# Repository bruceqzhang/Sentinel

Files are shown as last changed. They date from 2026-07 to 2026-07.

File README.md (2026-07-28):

# Sentinel - Remote-Controlled FPV Tank

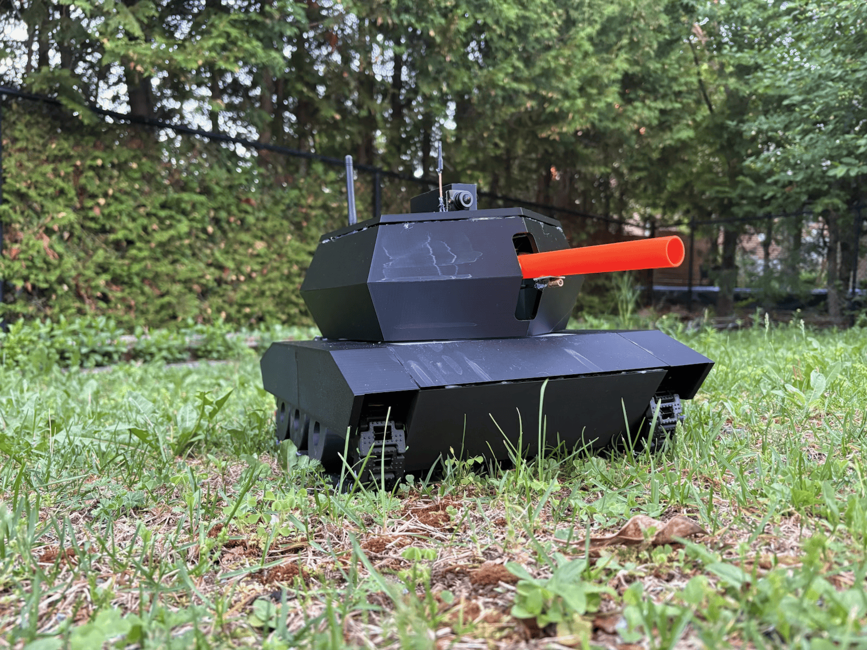
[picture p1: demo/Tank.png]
Finished Tank Design


Sentinel is a custom-built tracked remote-controlled vehicle designed and engineered from the ground up. The project combines mechanical design, embedded systems, wireless communication, and robotics into a single platform.

Built as a personal engineering challenge, Sentinel features a 3D-printed chassis, tracked drivetrain, 2.4 GHz wireless control system, 5.8 GHz FPV camera system, and a rotating Nerf turret. The tank is controlled by an Arduino-based embedded system, with future plans for onboard computer vision and autonomous capabilities using a Raspberry Pi.

The project involved designing the mechanical structure in CAD, fabricating custom parts, integrating electronics, developing the control software, and debugging a complex system of motors, sensors, and communication protocols.

## Motivation

Sentinel began as a challenge taken by two friends to build something beyond a typical classroom robot. Rather than creating a simple automated device, we wanted to explore how mechanical design, electronics, and software could come together in a complete robotics system.

## Features
- Custom 3D-printed tracked chassis
- Wireless remote control using 2.4 GHz communication
- Live 5.8 GHz analog FPV video transmission
- 360° rotating turret mechanism
- Arduino-based motor and actuator control
- Modular electronics and power distribution system
- Designed for future computer vision integration

## Technologies Used

### Hardware
- Arduino UNO R4 WiFi
- nRF24L01 wireless modules
- FPV camera, FPV monitor, and 5.8 GHz video transmitter
- Xbox controller
- DC gear motors and drivers
- Servo motors
- Stepper motor and driver
- 7.4 V 2S Li-ion battery supply
- Custom 3D-printed components

### Software
- Arduino C/C++
- Libraries including RF24, Servo, SPI, AccelStepper, XBOXONE from USB Host Shield 2.0

## Additional Resources

### CAD: 
[Onshape Project](https://cad.onshape.com/documents/b79e3abf584a43eee74fb859/w/d53a2419a0c5a431a686b558/e/01db5a0ad86b4068f335d182)  

### Weekly Journals:
[Week 1](https://docs.google.com/document/d/17Ajz8vXUG7C8QsSIpln7xRcLZVNVRcxvSVOUbZ24IYE/edit?usp=drive_link)  
[Week 2](https://docs.google.com/document/d/1W2MT0a_K2rhyGGTUNjvPy9FhipLKN2GWRZDyP753SX8/edit?usp=drive_link)  
[Week 3](https://docs.google.com/document/d/1quGVF-udUrTEX0IsD0kGBSyIRfxL883lqCnuZsB9mRc/edit?usp=drive_link)  
[Week 4](https://docs.google.com/document/d/1nc7bcCtwF5eugCoS6nO4E-aOTwUAF1d3NM4IUmDgt2E/edit?usp=drive_link)  
[Week 5](https://docs.google.com/document/d/1DuefWYwJcpw5OrmmurFnuGTMt__FWnk-4Q0KD2fvWug/edit?usp=drive_link)  
[Week 6](https://docs.google.com/document/d/11cAzaXNtNuGknSWchcGKMZekuylMzRt6ZZdopK9-in4/edit?usp=drive_link)  
[Week 7](https://docs.google.com/document/d/1Xcf18F4qVJCFmCrfTtPlUHFmC-JLRS2L01wTzXku7aY/edit?usp=drive_link)  
[Week 8](https://docs.google.com/document/d/1gu44P50zj96eCYETs0mco7hnURLjBjI5FsbhsaJNU7Q/edit?usp=drive_link)  
[Week 9](https://docs.google.com/document/d/1yQiESRAvD3YaRqxrGDqdF1br9n9rZQMoo9KKtbfv1E4/edit?usp=drive_link)  
[Week 10](https://docs.google.com/document/d/1YnJN5dJ7Cn3t6fgoHze17Jr2m_I_HSLMdpS_-rjgBwo/edit?usp=drive_link)  
  
### Course Reflection:
[Reflection](https://docs.google.com/document/d/1j7IExLx8Kn-AHnMsANZGUDmCsnGpeQEc7mS2ZHUMuxA/edit?usp=sharing)

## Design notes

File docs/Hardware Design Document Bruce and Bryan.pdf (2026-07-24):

Hardware Design Document for Sentinel

# Hardware Design Document

# Sentinel Final Version

# Bryan Zhang, Bruce Zhang

# TEJ4M, Mr. Roller

# Friday, June 19, 2026

____________________________________________________________________________________
June 19, 2026 | Page 1/25

## Table of Contents

PROJECT

OVERVIEW |
Development Process and Consulted Resources |

Block

Testing of Functional Requirements |
Testing of Hardware Requirements |
Testing of User Interface Requirements |
Testing of Hardware Interface Requirements |

APPENDIX B: Reflection of

Learning | 18 APPENDIX C:

Tank

Code |
Controller Code |
June 19, 2026 | Page 2/25

## Introduction

### Project Overview

The Sentinel is a remotely operated robotic toy tank designed to combine entertainment and practical engineering in a single platform. Intended for hobbyists, students, and anyone curious about robotics, the Sentinel replicates many features of a real tank: rubber-tracked drive powered by two independent 6V JGB37-550 DC gear motors, a continuously rotating turret driven by a 28BYJ-48 stepper motor, an MG996R servo-controlled barrel with adjustable elevation, and a flywheel-based dart launcher capable of firing Nerf darts from a standard magazine. The tank is constructed primarily from 3D-printed PLA components, housing all electronics within a compact chassis powered by a 7.4V 2S Li-ion battery.
The operator controls the tank through a wired Xbox One controller attached to a custom 3D-printed handheld controller unit, which communicates wirelessly with the tank over a 2.4 GHz nRF24L01+PA+LNA radio link. Simultaneously, the operator receives a live first-person video feed transmitted wirelessly at 5.8 GHz from a RunCam Phoenix 2 FPV camera mounted on the tank to a SoloGood FPV monitor attached to the controller—allowing the tank to be driven effectively from far away and out of direct line of sight. The controller unit is built around an Arduino Uno microcontroller paired with a USB Host Shield, while the tank itself is controlled by a second Arduino Uno responsible for all motor, servo, and actuator outputs.
A full Hardware Requirements Specification (HRS) was written prior to this document and is available for reference, detailing all functional, hardware, and interface requirements agreed upon with the project stakeholder. The Preliminary Design Document (PDD) builds on those requirements with detailed sub-circuit descriptions, interface definitions, component-level calculations, and a project schedule covering assembly through to final testing. This Hardware Design Document (HDD) reflects the build process and changes we made to our design.

### Development Process and Consulted Resources

Developed by Bruce Zhang and Bryan Zhang, these two friends were responsible for the design, assembly, wiring, and coding of the project. This process was lengthy, tedious, and involved a lot of help from external sources. For the design, the inspiration for this project came from toys and projects posted on Reddit and YouTube, which had much more complex and cool designs but demonstrated the potential and possibilities for the project. Alvin Ren and Felix Shen, two close friends, printed the parts for the assembly, using their 3D printers at home. Other mentors and friends were consulted for guidance, like Mr. Roller, who also provided parts in addition to his expertise. For parts of the design, assembly, and programming, AI agents like ChatGPT, Gemini, and Claude were used to aid and fast-track the development process. For example, Gemini was often used to generate programs to test individual components, enabling faster, more rigorous testing. Likewise, ChatGPT was often consulted for advice and guidance: making the design from scratch and finding the perfect components was often risky, so it helped with research and confirming design choices. Additionally, some firmware and third-party programs were required for the project. The CAD of the project was created in Onshape, and the code runs on the Arduino IDE, using common third-party libraries like the AccelStepper, RF24, and

June 19, 2026 | Page 3/25

XBOXONE (from USB Host Shield 2.0) libraries. Some of these libraries provided example sketches, too, which enabled quick, efficient debugging, testing, and even learning.

## Block Diagram

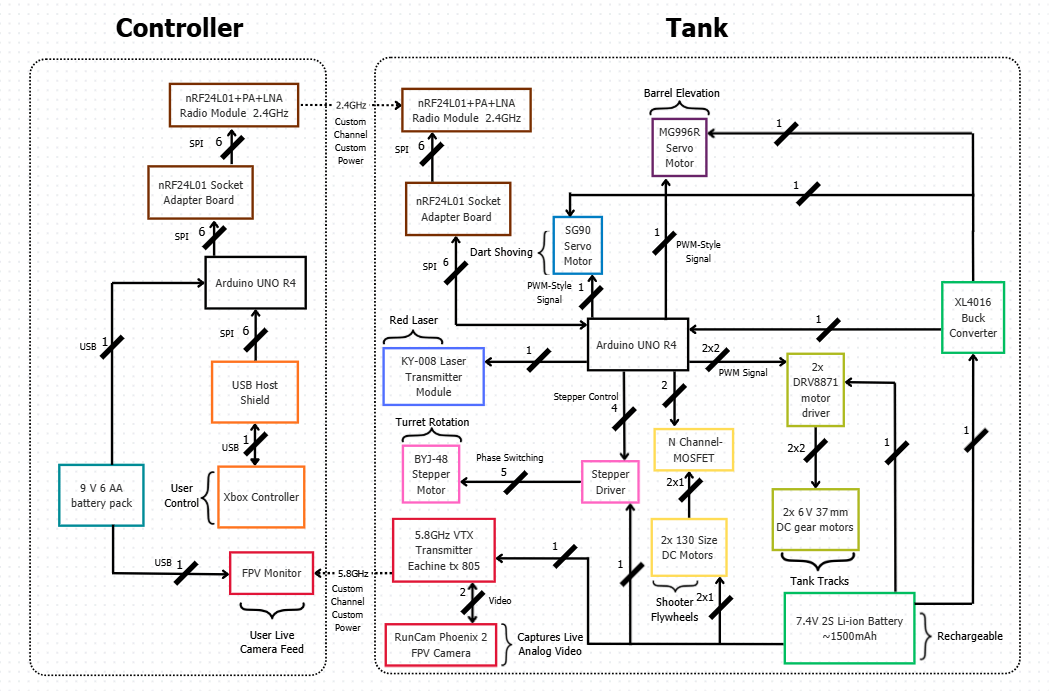
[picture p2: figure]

June 19, 2026 | Page 4/25

## User’s Guide

Toggle Switch
This switch is located on the tank chassis and turns the entire tank system on or off.

Rechargeable Battery
This plug is located next to the toggle switch on the tank chassis and allows users to recharge the Sentinel’s 7.4 lithium-ion battery with an XH-3Pin charger.

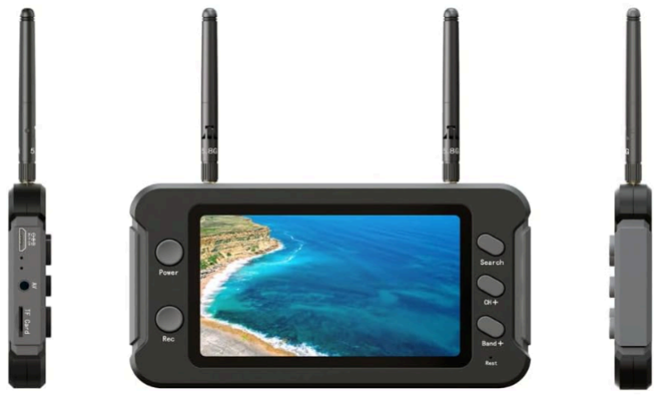
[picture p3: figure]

Plug-In Battery
This power supply activates the Xbox controller and the radio system. Plug in the barrel jack into the Arduino Uno R3 to initiate radio communication. The 6 AA batteries are non-rechargeable and may need to be replaced.

Monitor Power
The Power button is used to turn on and off the monitor. The monitor has its own rechargeable, internal power supply. Charge the monitor through the USB micro port on the side of the monitor.

Monitor Connection
The Search button is used to automatically search for the tank’s video stream. Once the tank is powered, the Search button allows the monitor to connect to the tank’s radio channel and stream the live video. The CH+ or Band+ buttons may be used for further customization of the connection.
June 19, 2026 | Page 5/25

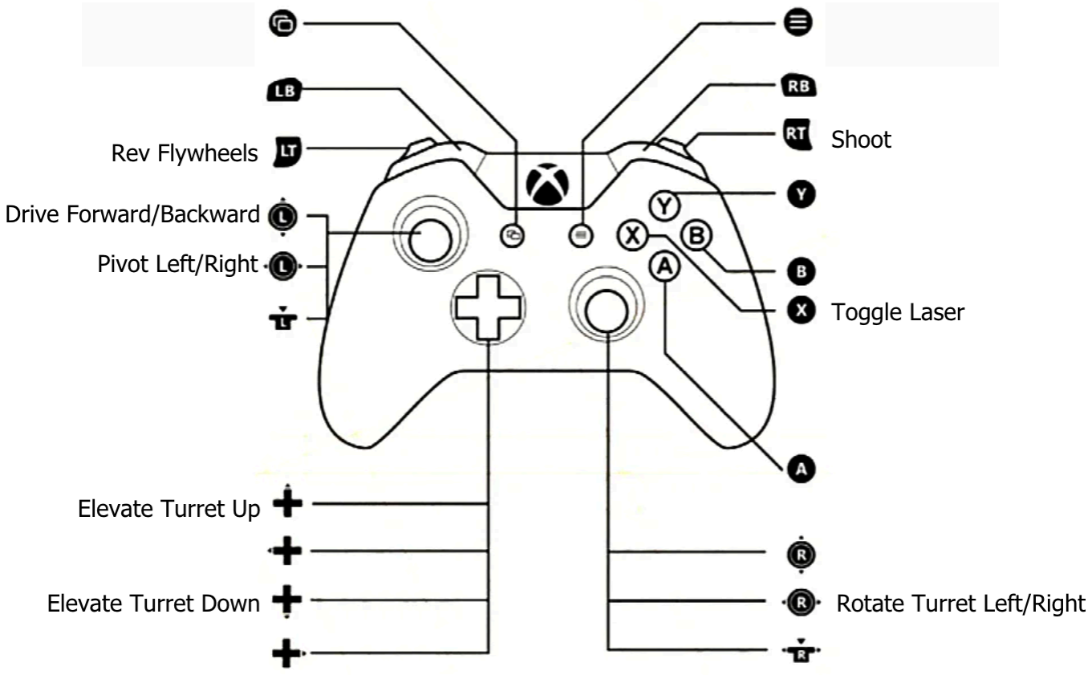
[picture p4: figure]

Left Joystick (Driving)
The left joystick controls the tank's movement using an arcade drive system. Moving the joystick forward and backward controls the speed and direction of both tracks, while moving it left or right controls turning. Combining both axes allows the tank to drive and turn simultaneously. A deadband and exponential response curve are used to improve control and prevent joystick drift.

Right Joystick (Turret Rotation)
The right joystick controls the turret's rotation. Moving the joystick left or right rotates the turret. Deadband and exponential controls improve precision.

Left Trigger (Flywheel Control)
The left trigger controls the flywheel motors used to launch darts. The farther the trigger is pressed, the faster the flywheels spin using PWM speed control. A deadband and response curve are included to provide smoother operation.

Right Trigger (Firing System)
The right trigger activates the dart-pushing servo to fire darts. The system only allows firing when the flywheels are already spinning, preventing jams and ensuring proper operation.

X Button (Laser Toggle)
The X button turns the turret-mounted laser on or off. The laser can be used to indicate where the turret is aiming.

Directional Pad (Barrel Elevation)
The D-Pad controls the barrel elevation. A quick press up or down moves the barrel up or down by increments of 3°. Holding a D-Pad direction continuously elevates the barrel at a constant speed.
June 19, 2026 | Page 6/25

## Appendix A: Beta Testing and Recording – Test Results

### Testing of Functional Requirements

Requirement Specification Reference | Requirement | Comments | Hardware Components Involved in Testing | Status | Date Tested
HRS-3.1.1 | The controller shall permit the user to remotely control the tank’s movements and features within an indoor range of at least 50 m | Control should be reliable: low latency, correct, long range, and without frequent disconnection/disto rtions | Xbox One controller (U5) Arduino Uno R3 microcontroller (U2 & U11) nRF24L01+ PA/LNA radio module (U6 & U15) USB Host Shield (U3) | Pass with Modification Control is reliable, low latency, correct but range is extremely limited | 06/18
HRS-3.1.2 | The controller shall provide a live video feed from the tank to a user within an indoor range of at least 50 m | Video should be reliable: low latency, correct, long range, and without frequent disconnection/disto rtions | RunCam Phoenix 2 (U12) Eachine TX805 5.8 GHz VTX (U9) Sologood FPV monitor (U1) | Pass with modification The video is low latency and correct. The range requirement was not met as the video could only reach a range of around 15m | 06/18
HRS-3.1.3 | The tank shall be able to move at different speeds and directions: it shall be able to go forward and backward, along with turning left and right by pivoting with tank drive mechanics. | Tank drive mechanics: turning and driving by controlling either left or right sides of the tank treads as separate units. E.g., turn left on the spot by moving left tracks backwards and right tracks forwards at full speeds | Arduino Uno R3 microcontroller (U11) JGB37-550 37mm motors (M4 & M6) DRV8871DDA DC Motor Driver (U14 & U17) | Pass Controlled by an arcade drive system, controlling the tank drive on one joystick | 06/18
HRS-3.1.4 | The tank shall be able to fire a Nerf foam dart at a distance of at least | | Size-130 DC motors (M5 & M7) Arduino Uno R3 microcontroller (U11) | Pass Shot 10 darts and measured their | 06/18
June 19, 2026 | Page 7/25

| 10 m away from the tank. | | IRLZ44N MOSFET (Q1) SG90 Servo motor (M1) | distances from the tank. Averaged the distance to be around 12-13m which is over the requirement of 10m.
HRS-3.1.5 | The tank shall have a capacity of at least 10 Nerf darts. | | | Pass Tank capacity depends on the Nerf magazine used, which can hold up to 10 Nerf darts. | 06/18
HRS-3.1.6 | The tank shall be able to fire at a maximum fire rate of at least 1 dart per second | | Size-130 DC motors (M5 & M7) Arduino Uno R3 microcontroller (U11) IRLZ44N MOSFET (Q1) SG90 Servo motor (M1) | Fail Fire rate is much slower than anticipated Closer to 3 seconds per dart | 06/18
HRS-3.1.7 | The tank’s turret shall be able to rotate continuously, past 360° of rotation | Continuous, infinite rotation | Arduino Uno R3 microcontroller (U11) BYJ-48 Stepper motor (M2) ULN2003 Stepper motor Driver (U8) | Pass Slip ring enables continuous, infinite rotation any direction | 06/18
HRS-3.1.8 | The tank’s turret shall be able to elevate at least 30° upwards from the base position | Base elevation could be below the horizontal (E.g. range of motion from -15° to 15°) | Arduino Uno R3 microcontroller (U11) MG996R Servo motor (M3) | Pass | 06/18
HRS-3.1.9 | The tank shall include a toggleable red laser beam that indicates where the turret is pointing | | Arduino Uno R3 microcontroller (U11) KY-008 Laser Transmitting Module (LD1) | Pass | 06/18
HRS-3.1.10 | The tank shall be able to independently identify human targets and enter a semi-autonomous mode that tracks targets with its turret | Barrel can move and rotate to aim at identified target independent of user control | | Fail Vision processing and Object detection were not incorporated into the design | N/A
June 19, 2026 | Page 8/25

### Testing of Hardware Requirements

Requirement Specification Reference | Requirement | Comments | Hardware Components Involved in Testing | Status | Date Tested
HRS-3.2.1 | The tank's outer body shall be made with 3D-printed parts with PLA | This includes the chassis, barrel, and rotating turret. | | Pass | 06/18
HRS-3.2.2 | The tank’s internal mechanisms, including but not limited to flywheels, custom gears, and shafts, shall be made with 3D-printed parts with PETG | Parts that are moving and need to withstand pressure and heat need to be printed with strong, PETG material | | Pass with Modification All parts were printed with PLA, which was strong enough Flywheels and flywheel cage were taken from Nerf blaster | 06/18
HRS-3.2.3 | The tank shall be driven on two rubber tank treads, attached to the body, that are tensioned by free-spinning wheels and powered by gears | Wheels will form the shape and guide the treads, while the gear will drive and physically shift each tread. | | Pass with Modification Tank treads are 3D printed with PLA | 06/18
HRS-3.2.4 | The tank shall have a chassis base that supports the turret and treads | Houses electronic components as well | | Pass | 06/18
HRS-3.2.5 | The tank shall have a turret on top of the chassis for firing | Includes barrel, housing for electronic components | | Pass | 06/18
HRS-3.2.6 | The tank shall be able to accommodate a Nerf magazine, which will be inserted on the side of the tank and can be easily removed or inserted. | 3D-printed custom magazine holder Magazine is spring loaded, containing Nerf darts | | Pass with Modification Any Nerf magazine is easily inserted on the top of the turret, not the side. | 06/18
HRS-3.2.7 | The tank shall be powered by a 7.4 V 2S Li-ion Battery | | 7.4 V 2S Li-ion Battery (BT2) | Pass | 06/18
HRS-3.2.8 | The tank shall use and contain an Arduino UNO R4 | | Arduino Uno R3 microcontroller (U11) | Pass with Modification The tank uses an | 06/18
June 19, 2026 | Page 9/25

| microcontroller. The Arduino will control and power certain input/output devices on the tank. | | | Arduino Uno 3 microcontroller. The Arduino Uno R4 is not used because they were short-circuited and damaged during previous testing.
HRS-3.2.9 | The tank shall use and contain a Raspberry Pi 4 for vision processing | | | Fail Design did not incorporate the Raspberry Pi 4 and vision processing because of time constraints. | N/A
HRS-3.2.10 | The tank’s Raspberry Pi 4 and Arduino Uno R4 microcontrollers shall be connected to a 5 V Buck Converter, which will be connected to the 7.4 V 2S Li-ion Battery. | | 7.4 V 2S Li-ion Battery (BT2) Arduino Uno R3 microcontroller (U11) XL4016 5 V Buck Converter (U16) | Pass with Modification Arduino Uno R3 microcontroller is connected to a 5V buck converter. No Raspberry Pi 2. | 06/18
HRS-3.2.11 | The tank shall contain a 28BYJ-48 stepper motor and a ULN2003 driver board for rotating the turret | | Arduino Uno R3 microcontroller (U11) BYJ-48 Stepper motor (M2) ULN2003 Stepper motor Driver (U8) | Pass | 06/18
HRS-3.2.12 | The tank shall contain an MG996R servo motor for changing the turret elevation | | Arduino Uno R3 microcontroller (U11) MG996R servo motor (M3) | Pass | 06/18
HRS-3.2.13 | The tank shall contain a SG90 servo motor for pushing darts to be shot out | | Arduino Uno R3 microcontroller (U11) SG90 servo motor (M1) | Pass The SG90 servo motor turns a gear in a rack-and-pinion mechanism to push the darts | 06/18
HRS-3.2.14 | The tank shall use two DRV8871DDA DC motor drivers to drive the two 6V-rated JGB37-550 37mm motors for moving | Motors have a torque of at least 0.35 Nm and an RPM of around 100-300. | Arduino Uno R3 microcontroller (U11) DRV8871DDA DC motor driver (U14 & U17) JGB37-550 37mm motors (M4 & M6) | Pass | 06/18
June 19, 2026 | Page 10/25

| the tank tracks
HRS-3.2.15 | The tank shall use one MOSFET to run the flywheel 130-size DC motors | Motors shall be able to reach speeds of at least 25000 rpm within 2-3 seconds, operating continuously for ≥ 60 seconds without overheating | Arduino Uno R3 microcontroller (U11) 130-size DC motors (M5 & M7) IRLZ44N MOSFET (Q1) | Pass with Modification RPM could not be tested reliably, but motors do reach substantial speed within 2-3 seconds and can operate continuously for over 60 seconds without overheating. | 06/18
HRS-3.2.16 | The tank shall have an nRF24L01+ PA/LNA Radio Module 2.4 GHz for receiving radio signals | | Arduino Uno R3 microcontroller (U11) nRF24L01+ PA/LNA Radio Module (U15) | Pass | 06/18
HRS-3.2.17 | The tank shall have a RunCam Phoenix 2 FPV Camera for analog video to the user | | RunCam Phoenix 2 (U12) Eachine TX805 5.8 GHz VTX (U9) Sologood FPV monitor (U1) | Pass | 06/18
HRS-3.2.18 | The tank shall have an Eachine TX805 5.8 GHz VTX to transmit analog video to the monitor | | RunCam Phoenix 2 (U12) Eachine TX805 5.8 GHz VTX (U9) Sologood FPV monitor (U1) | Pass | 06/18
HRS-3.2.19 | The tank shall have a mounted digital USB AverMedia PW313 Webcam to the turret that is connected to the Raspberry Pi 4 for vision processing | | | Fail Vision processing and object detection with the digital camera and the Raspberry Pi 4 were not incorporated into the design | N/A
HRS-3.2.20 | The controller shall have an Arduino Uno R4 microcontroller | | Arduino Uno R3 microcontroller (U2) | Pass with modification: The controller uses an Arduino Uno R3. | 06/18
HRS-3.2.21 | The controller shall contain a USB Host Shield connecting | USB Host Shield powers and transfers USB data | Arduino Uno R3 microcontroller (U2) USB Host Shield (U3) | Pass | 06/18
June 19, 2026 | Page 11/25

| the microcontroller to the Xbox controller | between Xbox controller and microcontroller | Xbox One Controller (U5)
HRS-3.2.22 | The controller’s Arduino shall be powered by a rechargeable power bank via USB | | Arduino Uno R3 microcontroller (U2) 9 V Power Supply (BT1) | Fail The Arduino Uno R3’s power supply is 9 V, 6 AA batteries through a barrel jack. | 06/18
HRS-3.2.23 | The controller shall have a wireless Xbox controller for user control | | Xbox One Controller (U5) | Pass Xbox controller is wired to the Arduino Uno R3, which sends radio packets wirelessly to the tank’s microcontroller | 06/18
HRS-3.2.24 | The controller shall have an nRF24L01+ PA/LNA Radio Module 2.4 GHz for transmitting radio signals | | Arduino Uno R3 microcontroller (U2) nRF24L01+ PA/LNA Radio Module (U6) | Pass | 06/18
HRS-3.2.25 | The controller shall contain a drone SoloGood 4.3” FPV monitor for receiving and streaming live video | | RunCam Phoenix 2 (U12) Eachine TX805 5.8 GHz VTX (U9) Sologood FPV monitor (U1) | Pass The monitor has an excellent, clear feed that has minimal latency. | 06/18
HRS-3.2.26 | The controller shall contain a 3D-printed PLA casing to hold the controller’s Arduino and power bank, and shall attach the monitor from HRS-3.2.25 to the controller | | | Pass with Modification The controller has a 3D printed container that holds the Sologood FPV monitor and the Xbox controller together. The Arduino, radio module, and 6 AA batteries as the 9 V power supply are glued onto the back of the monitor. | 06/18

### Testing of User Interface Requirements

Requirement
Specification
Reference
Requirement | Comments | Hardware Components Involved
Status | Date
Tested
June 19, 2026 | Page 12/25

| | | in Testing
HRS-3.3.1 | The tank shall be controlled by a user-operated remote Xbox controller that sends 2.4 GHz radio signals to control the tank. | Using nRF24L01+ PA/LNA radio modules, with Arduino UNO R4s, USB Host Shield, and standard Xbox wireless controllers The user can control the tank remotely | Xbox One controller (U5) Arduino Uno R3 microcontroller (U2 & U11) nRF24L01+ PA/LNA radio module (U6 & U15) USB Host Shield (U3) | Pass | 06/18
HRS-3.3.2 | The tank shall stream live, analog video through wireless 5.8 GHz radio signals to an FPV monitor | Monitor is attached to the controller The user can watch the live video stream of the tank while they are controlling it | Eachine TX805 5.8 GHz VTX (U9) Sologood FPV monitor (U1) RunCam Phoenix 2 (U12) | Pass | 06/18
HRS-3.3.3 | The tank shall be able to move its treads via joystick, radio frequency remote control | Tank drive, using an arcade drive control system where one joystick controls both tank treads Left joystick on Xbox controller | Xbox One controller (U5) Arduino Uno R3 microcontroller (U2 & U11) nRF24L01+ PA/LNA radio module (U6 & U15) USB Host Shield (U3) JGB37-550 37mm motors (M4 & M6) DRV8871DDA DC Motor Driver (U14 & U17) | Pass | 06/18
HRS-3.3.4 | The tank shall be able to spin the flywheels when the user holds a trigger down on a radio frequency remote controller. | Flywheels will spin at different speeds based on how much the trigger is held down Left trigger on Xbox controller | Xbox One controller (U5) Arduino Uno R3 microcontroller (U2 & U11) nRF24L01+ PA/LNA radio module (U6 & U15) USB Host Shield (U3) Size-130 DC motors (M5 & M7) IRLZ44N MOSFET (Q1) | Pass with Modification As outlined in HRS-3.4.2, flywheel motors only spin at max speed. | 06/18
June 19, 2026 | Page 13/25

HRS-3.3.5 | The tank shall be able to shoot a dart when the user presses a button on a radio frequency remote controller. If the user holds the button, the tank shall be able to continuously fire darts. This feature will only work if flywheels are activated as outlined in HRS-3.3.4 | Right trigger on Xbox controller | Xbox One controller (U5) Arduino Uno R3 microcontroller (U2 & U11) nRF24L01+ PA/LNA radio module (U6 & U15) USB Host Shield (U3) Size-130 DC motors (M5 & M7) IRLZ44N MOSFET (Q1) SG90 Servo motor (M1) | Pass | 06/18
HRS-3.3.6 | The turret on the tank shall be able to rotate when the user moves the joystick of a radio frequency remote control left and right. The barrel on the tank shall be able to move up and down when the user moves the same joystick up and down. | Left/right yaw movement and up/down pitch movement on same joystick Right joystick on Xbox controller | Xbox One controller (U5) Arduino Uno R3 microcontroller (U2 & U11) nRF24L01+ PA/LNA radio module (U6 & U15) USB Host Shield (U3) BYJ-48 Stepper motor ULN2003 Stepper motor driver MG996R Servo motor | Pass with Modification Left/right yaw movement on the right joystick Up/down pitch movement on up/down D-pads | 06/18
HRS-3.3.7 | The tank shall be able to toggle a laser on or off with a radio frequency remote controller. The laser should indicate where the dart will hit. | Face button X on the Xbox controller | Xbox One controller (U5) Arduino Uno R3 microcontroller (U2 & U11) nRF24L01+ PA/LNA radio module (U6 & U15) USB Host Shield (U3) KY-008 Laser Transmitting Module (LD1) | Pass Not perfect accuracy regarding the Nerf dart, but functionality remains. | 06/18
HRS-3.3.8 | The tank shall be able to enter and exit an autonomous mode once a user toggles a button on a radio frequency remote controller. The autonomous mode allows the tank to move and | Face button A on the Xbox controller | | Fail Autonomous control and vision processing were not incorporated in the final design.
June 19, 2026 | Page 14/25

| aim at targets independent of user control, but it will not be able to fire.
HRS-3.3.9 | The tank shall automatically power off and cease movement if it loses communication with the remote controller | If signals become distorted or the tank stops receiving signals, such as if something breaks or the tank goes out of range, the tank stops all movements | Arduino Uno R3 (U11) nRF24L01+ PA/LNA radio module (U15) | Pass Tested Safe Stop function that consistently pauses all Arduino signals until radio communication is reestablished. | 06/18
HRS-3.3.10 | The tank shall have a physical on/off switch that allows users to power/start the tank and power off the tank. | Switch to connect or disconnect battery | Toggle Switch (SW1) | Pass | 06/18
HRS-3.3.11 | The tank shall be able to fire Nerf darts at users and non-user targets and hit them | Physical user-system interaction | Arduino Uno R3 microcontroller (U11) Size-130 DC motors (M5 & M7) IRLZ44N MOSFET (Q1) SG90 Servo motor (M1) | Pass Able to shoot Nerf darts and hit targets. | 06/18

### Testing of Hardware Interface Requirements

Requirement Specification Reference | Requirement | Comments | Hardware Components Involved in Testing | Status | Date Tested
HRS-3.4.1 | The tank’s Arduino microcontroller shall drive both DRV8871DDA DC motor drivers with a PWM signal, which in turn will drive 2 6V-rated JGB37-550 37mm motors connected to gears, which will drive the tank treads | | Arduino Uno R3 microcontroller (U11) JGB37-550 37mm motors (M4 & M6) DRV8871DDA DC Motor Driver (U14 & U17) | Pass Tested driving of tank treads in both directions on the ground | 06/18
June 19, 2026 | Page 15/25

HRS-3.4.2 The tank’s Arduino microcontroller shall drive the MOSFET with a PWM signal, which will drive two 130-Size High-RPM DC Motors, which will be connected to the flywheels.

Arduino Uno R3
microcontroller (U11)
Size-130 DC motors
(M5 & M7)
IRLZ44N MOSFET
(Q1)

Pass with Modification

The tank’s Arduino
microcontroller drives
the MOSFET with a
digital signal, which
drives two 130-Size
DC motors.

This is because on
the Arduino Uno R3,
all the PWM pins are
used by the drivetrain
motors and SPI
communication, so
this connection was
moved to digital pin
7. Minimal
functionality lost.

06/18

HRS-3.4.3 | The tank’s Arduino microcontroller shall drive the laser module with a digital output signal | | Arduino Uno R3 microcontroller (U11) KY-008 Laser Transmitting Module (LD1) | Pass | 06/18
HRS-3.4.4 | The Arduino microcontroller shall control a stepper driver that will drive a stepper motor that will be used to rotate the turret | Logic inputs from the microcontroller into the driver determining speed, direction, enabling, step resolution The driver controls the motor by phase power switching that connects 5V to ground on specified phases, individual ends of the motor coils. | Arduino Uno R3 microcontroller (U11) BYJ-48 Stepper motor (M2) ULN2003 Stepper motor driver (U8) | Pass The stepper motor is much slower than expected, with an approximate turret rotation speed of 1 rotation every 8 seconds. | 06/18
HRS-3.4.5 | The tank’s Arduino microcontroller shall drive a servo motor with a PWM signal that will change the elevation of the barrel. | | Arduino Uno R3 microcontroller (U11) MG996R Servo motor (M3) | Pass | 06/18
HRS-3.4.6 | The tank's Arduino microcontroller shall drive a servo motor with a PWM signal that will push the dart into the flywheels | | Arduino Uno R3 microcontroller (U11) SG90 Servo motor (M1) | Pass | 06/18
June 19, 2026 | Page 16/25

HRS-3.4.5 | The tank’s Arduino UNO R4 communicates with the Raspberry Pi 4 by Serial UART over USB | | | Fail The Raspberry Pi 4 was not incorporated into the final design. | N/A
HRS-3.4.7 | The tank shall have a digital webcam connected to a Raspberry Pi 4 via USB for vision processing. | | | Fail The Raspberry Pi 4 was not incorporated into the final design. | N/A
HRS-3.4.8 | The tank’s Arduino microcontroller shall receive and interpret radio signals with an nRF24L01+PA+LNA radio module by SPI | | Arduino Uno R3 microcontroller (U11) nRF24L01+ PA/LNA radio module (U15) | Pass Packets were programmed to contain a specific sequence of information and address. Had to use low power mode to avoid loss of signal integrity | 06/18
HRS-3.4.9 | The controller’s Arduino microcontroller shall transmit and package radio signals with an nRF24L01+PA/LNA radio module by SPI | | Arduino Uno R3 microcontroller (U2) nRF24L01+ PA/LNA radio module (U6) USB Host Shield (U3) | Pass Packets were programmed to contain a specific sequence of information and address Had to use low power mode to avoid loss of integrity | 06/18
HRS-3.4.10 | The tank’s radio module shall receive transmitted radio signals from the controller’s radio module through wireless 2.4 GHz radio signals | Radio waves will be modulated and customized data packets Antenna-to-antenna communication | Arduino Uno R3 microcontroller (U2 & U11) nRF24L01+ PA/LNA radio module (U6 & U15) | Pass Tested with example sketches of both transceivers communicating. | 06/18
HRS-3.4.11 | The controller’s Arduino microcontroller shall interface with a USB Host Shield by SPI | Note: both the radio module and host shield will need to share some SPI pins on the controller’s microcontroller, but differ in address pins | Arduino Uno R3 microcontroller (U2) USB Host Shield (U3) | Pass | 06/18
June 19, 2026 | Page 17/25

HRS-3.4.12 | The controller’s USB Host Shield will connect the Xbox Controller to the microcontroller by USB | | XBox One controller (U5) Arduino Uno R3 microcontroller (U2) USB Host Shield (U3) | Pass | 06/18
HRS3.4.13 | The tank shall have an FPV camera connected to a 5.8 GHz VTX transmitter | Camera sends analog composite video to the VTX | Eachine TX805 5.8 GHz VTX (U9) RunCam Phoenix 2 (U12) | Pass | 06/18
HRS3.4.14 | The tank’s video transmitter will send 5.8 GHz video signal to an FPV monitor on the controller | Analog video transmitted as radio waves Monitor and VTX need to be set to be on the same channel (frequency) VTX can switch power of signal (25 mw, 200 mW, 600 mW, 800 mW), changing range, power usage, and signal integrity | Eachine TX805 5.8 GHz VTX (U9) Sologood FPV Monitor (U1) RunCam Phoenix 2 (U12) | Pass Had to use 25 mW power mode because the other modes would be too hot | 06/18

## Appendix B: Reflection of Learning

## Appendix C: Code

### Tank Code

// ============================================================================= // Sentinel Tank
// Bryan Zhang, Bruce Zhang
// June 19, 2026
//
// A program designed to receive radio signals containing data from the Sentinel // controller, translating the data into actuator and motor outputs, controlling // the tank according to user control.
//
// Hardware:
// | - Arduino UNO R3 (U11)
// | - KY-008 Laser Transmitting Module (LD1)
// | - SG90 Servo Motor (M1)
// | - BYJ-48 Stepper Motor (M2)
// | - MG996R Servo Motor (M3)
// | - JGB37-550 37mm DC Motors (M4 & M6)
// | - Nerf Size-130 DC Motors (M5 & M7)
// =============================================================================

#include <SPI.h>

June 19, 2026 | Page 18/25

#include <RF24.h>

#include <Servo.h>

#include <AccelStepper.h>

// ── Pin definitions ─────────────────────────
#define NRF_CSN_PIN | 4

#define NRF_CE_PIN | 8

#define MOTOR_A_IN1 | 5

#define MOTOR_A_IN2 | 3

#define MOTOR_B_IN1 | 9

#define MOTOR_B_IN2 | 6

#define FLYWHEEL_PIN 7

#define LASER_PIN | 2

#define SHOVER_PIN | A4

#define BARREL_PIN | A5

#define STEP_PIN1 | A0

#define STEP_PIN2 | A1

#define STEP_PIN3 | A2

#define STEP_PIN4 | A3

// ── Buttons ─────────────────────────────
#define BTN_X | (1 << 1)

#define BTN_DPAD_UP | (1 << 6)

#define BTN_DPAD_DOWN (1 << 7)

// ── Payload ───────────────────────────── struct Payload {
int16_t leftX;
int16_t leftY;
int16_t rightX;
int16_t rightY;
uint8_t leftTrig;
uint8_t rightTrig;
uint8_t buttons;
};

// ── Forward declaration ─────────────────
void handlePacket(const Payload &pkt, unsigned long now);

// ── Radio ───────────────────────────────
RF24 radio(NRF_CE_PIN, NRF_CSN_PIN);
const byte ADDRESS[6] = "SNTL1";

// ── Servos ────────────────────────────── Servo shoverServo;
Servo barrelServo;

// ── Stepper ─────────────────────────────
#define STEPS_PER_REV 2048

AccelStepper turretStepper(AccelStepper::HALF4WIRE, STEP_PIN1, STEP_PIN3, STEP_PIN2, STEP_PIN4);

// ── State ───────────────────────────────
bool laserOn = false;
bool flywheelsOn = false;
bool shootActive = false;

int barrelAngle = 15;

June 19, 2026 | Page 19/25

const int BARREL_MIN = 0;
const int BARREL_MAX = 30;

long turretTarget = 0;

// ── timing ────────────────────────────── unsigned long lastPacketTime = 0;
const unsigned long WATCHDOG_MS = 1000;

unsigned long lastShoveTime = 0;
const unsigned long SHOVE_INTERVAL = 500; bool shoverState = false;

// ── startup safety system ────────── bool systemReady = false;
uint8_t packetCount = 0;
uint8_t lastButtons = 0;

void setMotor(uint8_t in1, uint8_t in2, int speed) { speed = constrain(speed, -255, 255);

if (speed >= 0) {
// Forward: IN1 handles direction (flat HIGH), IN2 handles speed via inverted PWM // This allows Pin 9 (IN1) to act as a pure digital pin
digitalWrite(in1, HIGH);
analogWrite(in2, 255 - speed);
}
else {
// Backward: IN1 goes LOW, IN2 handles raw speed PWM digitalWrite(in1, LOW);
analogWrite(in2, -speed);
}
}

// ── Arcade drive ────────────────────────
void arcadeDrive(int16_t joyY, int16_t joyX, int &leftOut, int &rightOut) { int throttle = map((long)joyY, -32767L, 32767L, -255L, 255L);
int turn = map((long)joyX, -32767L, 32767L, -255L, 255L);

leftOut = constrain(throttle + turn, -255, 255);
rightOut = constrain(throttle - turn, -255, 255);
}

// ── safe stop ───────────────────────────
void safeStop() {
setMotor(MOTOR_A_IN1, MOTOR_A_IN2, 0); setMotor(MOTOR_B_IN1, MOTOR_B_IN2, 0); analogWrite(FLYWHEEL_PIN, 0);

shoverServo.write(0);
digitalWrite(LASER_PIN, LOW);

laserOn = false;
flywheelsOn = false;
shootActive = false;
}

// ── setup ─────────────────────────────── void setup() {

June 19, 2026 | Page 20/25

pinMode(MOTOR_A_IN1, OUTPUT); pinMode(MOTOR_A_IN2, OUTPUT); pinMode(MOTOR_B_IN1, OUTPUT); pinMode(MOTOR_B_IN2, OUTPUT);

pinMode(FLYWHEEL_PIN, OUTPUT); pinMode(LASER_PIN, OUTPUT);

// immediate safe servo position ── delay(300);
shoverServo.write(0);
barrelServo.write(barrelAngle); shoverServo.attach(SHOVER_PIN); barrelServo.attach(BARREL_PIN);

safeStop();

turretStepper.setMaxSpeed(1000); turretStepper.setAcceleration(400);

radio.begin();
radio.setPALevel(RF24_PA_LOW); radio.setDataRate(RF24_250KBPS); radio.setChannel(76);
radio.openReadingPipe(1, ADDRESS); radio.startListening();

delay(1000); // full power stabilization delay

systemReady = true;
lastPacketTime = millis();
}

// ── Loop ──────────────────────────────── void loop() {

if (!systemReady) return;

unsigned long now = millis();

if (now - lastPacketTime > WATCHDOG_MS) { safeStop();
}

Payload pkt;
if (radio.available()) {
radio.read(&pkt, sizeof(pkt)); lastPacketTime = now;
handlePacket(pkt, now);

}

// ── shover ───────────────────────────
if (shootActive && flywheelsOn) {
if (now - lastShoveTime > SHOVE_INTERVAL) { lastShoveTime = now;
shoverState = !shoverState; shoverServo.write(shoverState ? 180 : 0); }
} else {
shoverServo.write(0);
June 19, 2026 | Page 21/25

shoverState = false;
}

// ── turret ─────────────────────────── turretStepper.run();
}

// ── packet handler ──────────────────────
void handlePacket(const Payload &pkt, unsigned long now) {

// ── ignore first packets ───────
if (packetCount < 10) {
packetCount++;
lastButtons = pkt.buttons; return;
}

uint8_t rising = pkt.buttons & ~lastButtons;

if (rising & BTN_X) {
laserOn = !laserOn;
digitalWrite(LASER_PIN, laserOn);
}

// ── barrel control ───────────────────
if (pkt.buttons & BTN_DPAD_UP)
barrelAngle = constrain(barrelAngle + 3, BARREL_MIN, BARREL_MAX);

if (pkt.buttons & BTN_DPAD_DOWN)
barrelAngle = constrain(barrelAngle - 3, BARREL_MIN, BARREL_MAX);

barrelServo.write(barrelAngle);

// ── drive ────────────────────────────
int leftSpeed, rightSpeed;
arcadeDrive(pkt.leftY, pkt.leftX, leftSpeed, rightSpeed);

setMotor(MOTOR_A_IN1, MOTOR_A_IN2, leftSpeed); setMotor(MOTOR_B_IN1, MOTOR_B_IN2, -rightSpeed);

// ── turret input ─────────────────────
if (abs(pkt.rightX) > 7500) {
turretTarget += map(pkt.rightX, -32767, 32767, -20, 20); }
turretStepper.moveTo(turretTarget);

// ── flywheels ──────────────── flywheelsOn = (pkt.leftTrig > 10);

if (flywheelsOn) {
digitalWrite(FLYWHEEL_PIN, HIGH); } else {
digitalWrite(FLYWHEEL_PIN, LOW);
}

shootActive = (flywheelsOn && pkt.rightTrig > 10);

lastButtons = pkt.buttons;
}
June 19, 2026 | Page 22/25

### Controller Code

// ============================================================================= // Sentinel Controller
// Bryan Zhang, Bruce Zhang
// June 19, 2026
//
// A program designed to transform user inputs on an Xbox Controller into radio
// information to be sent over a 2.4 GHz channel communication link to the Sentinel, // allowing user control of the tank.
//
// Hardware:
// | - Arduino UNO R3 (U2)
// | - USB Host Shield (U3) → D10 CS, D11 MOSI, D12 MISO, D13 SCK, D2 INT
// | - Xbox One Controller (U5) | → USB Host Shield
// | - nRF24L01+PA+LNA (U6) → D9 CSN, D8 CE, D11 MOSI, D12 MISO, D13 SCK
//
// Control Scheme:
// | Left Joystick Y → Drive forward / backward
// | Left Joystick X → Pivot / turn (tank drive)
// | Right Joystick X → Rotate turret
// | Left Trigger | → Rev flywheels (analog speed)
// | Right Trigger | → Shoot dart (only fires if flywheels spinning)
// | X | → Toggle laser
// | D-Pad U/D | → Barrel elevation setpoints (3° increments)
// =============================================================================

#include <XBOXONE.h>

#include <SPI.h>

#include <RF24.h>

// ── nRF24L01 pins ──────────────────────────────────────────────────────────── #define NRF_CE_PIN 8
#define NRF_CSN_PIN 4

// ── Radio ───────────────────────────────────────────────────────────────────── RF24 radio(NRF_CE_PIN, NRF_CSN_PIN);
const byte ADDRESS[6] = "SNTL1";

// ── USB / Xbox ──────────────────────────────────────────────────────────────── USB Usb;
XBOXONE Xbox(&Usb);

// ── Payload struct (max 32 bytes) ───────────────────────────────────────────── // Total: 2+2+2+2+1+1+1 = 11 bytes
struct Payload {
int16_t leftX; | // -32768 to 32767
int16_t leftY;
int16_t rightX;
int16_t rightY;
uint8_t leftTrig; | // 0-255
uint8_t rightTrig; | // 0-255
uint8_t buttons;
};

// ── Button bitmask positions ──────────────────────────────────────────────────
#define BTN_X | (1 << 1)

#define BTN_DPAD_UP | (1 << 6)

#define BTN_DPAD_DOWN (1 << 7)

// ── Deadband ──────────────────────────────────────────────────────────────────

June 19, 2026 | Page 23/25

#define DEADBAND 7500

// ── Exponential curve helper ────────────────────────────────────────────────── // Applies a mild square curve while preserving sign.
// Input/output: -32767 to 32767
int16_t expoCurve(int16_t raw) {
if (abs(raw) < DEADBAND) return 0;
float n = (float)raw / 32767.0f;
// blend: 50% linear + 50% cubic
float curved = 0.5f * n + 0.5f * n * n * n; return (int16_t)(curved * 32767.0f);
}

// ── Setup ───────────────────────────────────────────────────────────────────── void setup() {
Serial.begin(115200);

// force both spi devices silent immediately pinMode(10, OUTPUT);
digitalWrite(10, HIGH); // De-select USB Host Shield pinMode(NRF_CSN_PIN, OUTPUT); digitalWrite(NRF_CSN_PIN, HIGH); // De-select nRF24L01 delay(100);

// initialize usb shield
Serial.println(F("Initializing USB Host Shield...")); if (Usb.Init() == -1) {
Serial.println(F("USB Host Shield did not start"));
while (1);
}
digitalWrite(10, HIGH); // Ensure it releases the SPI bus immediately after Serial.println(F("USB Host Shield started"));

// initialize nrf24l01
Serial.println(F("Initializing nRF24L01...")); if (!radio.begin()) {
Serial.println(F("nRF24L01 not found")); while (1);
}
radio.setPALevel(RF24_PA_LOW); radio.setDataRate(RF24_250KBPS); radio.setChannel(76);
radio.openWritingPipe(ADDRESS);
radio.stopListening();

digitalWrite(NRF_CSN_PIN, HIGH); // Ensure radio releases the bus Serial.println(F("nRF24L01 ready — Sentinel Controller online"));

Xbox.setRumbleOff();
}

// ── State for non-blocking transmission timer ─────────────────────────────── unsigned long lastTxTime = 0;
const unsigned long TX_INTERVAL_MS = 20;

// ── Loop ───────────────────────────────────────────────────────────────────── void loop() {
Usb.Task();

if (!Xbox.XboxOneConnected) return;

June 19, 2026 | Page 24/25

// ── Read raw joystick values ──────────────────────────────────────────────── int16_t rawLX = Xbox.getAnalogHat(LeftHatX);
int16_t rawLY = Xbox.getAnalogHat(LeftHatY);
int16_t rawRX = Xbox.getAnalogHat(RightHatX);
int16_t rawRY = Xbox.getAnalogHat(RightHatY);

// Apply deadband + expo curve
int16_t lx = expoCurve(rawLX);
int16_t ly = expoCurve(rawLY); int16_t rx = expoCurve(rawRX); int16_t ry = expoCurve(rawRY);

// ── Triggers ─────────────────────────────────────────────────────────────── uint8_t lt = (uint8_t)map(Xbox.getButtonPress(LT), 0, 1023, 0, 255);
uint8_t rt = (uint8_t)map(Xbox.getButtonPress(RT), 0, 1023, 0, 255);

// ── Button clicks ───────
static uint8_t accumulatedButtons = 0;

// Check clicks continuously on every fast loop pass
if (Xbox.getButtonClick(X)) | accumulatedButtons |= BTN_X;
if (Xbox.getButtonClick(UP)) | accumulatedButtons |= BTN_DPAD_UP;
if (Xbox.getButtonClick(DOWN)) | accumulatedButtons |= BTN_DPAD_DOWN;

// ── Non-Blocking Transmission Engine ─────────────────────────────────────── unsigned long now = millis();
if (now - lastTxTime >= TX_INTERVAL_MS) {
lastTxTime = now;

// Pack the payload using our accumulated buttons Payload pkt;
pkt.leftX | = lx;
pkt.leftY | = ly;
pkt.rightX | = rx;
pkt.rightY | = ry;
pkt.leftTrig = lt;
pkt.rightTrig = rt;
pkt.buttons = accumulatedButtons;
// Send data over nRF24
bool ok = radio.write(&pkt, sizeof(pkt));
// Clear the accumulator so we can collect fresh clicks for the next packet accumulatedButtons = 0;

}
}
June 19, 2026 | Page 25/25

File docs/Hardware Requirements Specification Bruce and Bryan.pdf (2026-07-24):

Hardware Requirements Specification for Sentinel

# Hardware Requirements Specification

# Sentinel Version 1.0

# Sunday, March 8, 2026

# Bryan Zhang, Bruce Zhang

# TEJ4M, Mr. Roller

____________________________________________________________________________________
March 9, 2026 | Page 1/16

## Table of Contents

1.1 PROJECT OVERVIEW |
1.2 PURPOSE AND SCOPE OF THIS SPECIFICATION |
2.1 PRODUCT CONTEXT |
2.2 USER CHARACTERISTICS |
2.3 ASSUMPTIONS/RISKS |
2.4 CONSTRAINTS |

2.5
DEPENDENCIES |
3.1 FUNCTIONAL REQUIREMENTS |
3.2 FUNCTIONAL REQUIREMENTS |
3.3 | USER | INTERFACE
REQUIREMENTS |
3.4 HARDWARE INTERFACES |
APPENDIX A. DEFINITIONS, ACRONYMS, AND ABBREVIATIONS |
APPENDIX B. REFERENCES |
March 9, 2026 | Page 2/16

## 1. Executive Summary

### 1.1 Project Overview

The Sentinel is a robotic toy tank that combines fun, engineering, and usefulness in one project. By letting kids or any bored adults get ahold of this engineering masterpiece, they can have fun or malice as required. The tank, which can shoot nerf darts at people, has many features like any real tank, including a rotational turret and tank tracks, and can be remotely controlled by a user who can watch a video stream connected to the tank and control it via a gaming controller.

### High-Level Block Diagram of the Sentinel

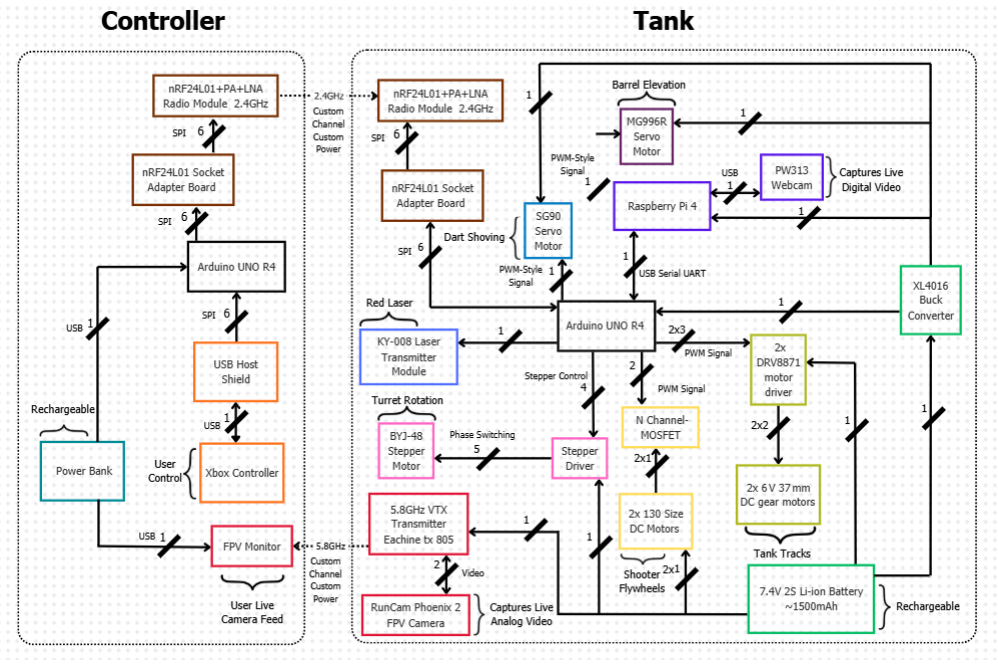
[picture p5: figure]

March 9, 2026 | Page 3/16

### 1.2 Purpose and Scope of this Specification

The purpose behind this project is to create a fun, meaningful toy that can bring joy to any customer interested in the capabilities of a hobby robot tank. As the designer of the Sentinel, we seek to build and assemble a functional robot that our clients and our manager will be satisfied with. Clients from the toy hobby RC and the toy manufacturing industry require a cheap toy that can shoot toy darts at human targets, with various other functional requirements, such as being able to stream a live video feed to a controller far away. Clients also require that this project meet most of the curriculum expectations of the Ontario TEJ4M course, covering many strands like circuitry and networking. Additionally, the manager requires an efficient assembly with cheap costs, meeting deadlines as outlined in the PDD. Specifically, this project shall be completed within a bit more than two months, with planning and delivery taking an extra two months in addition to this assembly period.

## 2. Product Description

The Sentinel is a hobby remote-controlled robotic tank system designed to emulate a real tank and its features while being a fun toy to play with. The Sentinel shall resemble a moving turret, made of a plastic frame with movable parts. The tank shall be controlled by a remote gaming controller, moving its tank tracks around, rotating a turret, and shooting Nerf darts. Moreover, the tank will stream a live video feed from the tank to the user through an FPV drone monitor, so the user can effectively control it from far away, out of sight. The Sentinel shall have many features. It can reload using magazines; it can use vision processing to autonomously identify human targets, aiming towards them; and it can even shoot Nerf darts rapidly in succession—automatically. Likewise, the tank will also contain many electronics and interfaces—both the controller and tank shall be largely Arduino-based but will also contain a Raspberry Pi 4, rechargeable batteries, radio modules, a drone camera and monitor, powerful motors, and more.

### 2.1 Product Context

As a partially autonomous, controllable tank, the Sentinel does not regularly interact or interface with any external third-party software or hardware: it is a self-contained, independent system that can be controlled by users. However, the fabrication of the Sentinel uses many outsourced parts and software to run the tank. For example, the tank shoots Nerf darts as its projectile, and the tank uses Arduino and Raspberry Pi microcontrollers to run software and control input and output devices. Additionally, the tank requires many consumer products in assembly, such as an Xbox controller, a Runcam Phoenix 2 drone camera, and a SoloGood drone monitor to control the tank.

### 2.2 User Characteristics

Ideally, the general customer would be any teenager or interested RC hobbyist who would be interested in playing with and using a toy remote-controlled tank. These hobbyists would be adult engineers, teenagers, or anyone trying to get in the field and learning about robotics or remote control. However, because the project’s user interface does not require any technical expertise, kids and almost any client simply looking for a fun time can use this product, even if they cannot understand or learn about the electronics and theory behind the Sentinel.

March 9, 2026 | Page 4/16

### 2.3 Assumptions/Risks

The following assumptions describe conditions expected to be true for the system during development and operation. These assumptions help define the environment and limitations under which the tank is designed to function

Assumption 1: It is assumed that the tank will operate in an indoor or well-controlled outdoor environment with minimal obstacles and hazards.

Assumption 2: It is assumed that the communication signal between the controller and the tank will remain within the intended operating range.

Assumption 3: It is assumed that the tank will not be exposed to water, extreme temperatures, or harsh environmental conditions.

Assumption 4: It is assumed that the operator has basic knowledge of how to control the tank.

Assumption 5: It is assumed that the components and wireless communication systems will perform according to their documented specifications. For example, the nRF24L01 + PA + LNA 2.4 GHz modules are expected to achieve a significant portion of their advertised maximum line-of-sight communication range under low-interference conditions.

The following risks describe potential issues that could affect the development or performance of the tank. These risks may impact progress, system reliability, or overall functionality if they occur.

Risk 1: Some electronic components that require purchase (such as the high-torque DC motors or USB host shield) may be unavailable or delayed in shipping.

Risk 2: The motors may not provide sufficient torque to move the tank if the final system weight is greater than expected.

Risk 3: Wireless communication may experience interference from other devices operating on similar frequencies.

Risk 4: Mechanical components such as motors, gears, or tracks may wear out or fail during extended use.

Risk 5: The 3D printed structural parts may not be strong enough and could crack or deform under stress during operation.

Risk 6: The system may experience overheating if motors, regulators, or other electronic components draw high current for extended periods.

### 2.4 Constraints

The following constraints define the limitations imposed on the design, components, and operation of the tank. These constraints must be considered during development to ensure the system functions as intended.

Constraint 1: The weight of the components on the tank must remain low enough so that the drive motors can move the tank efficiently, limiting the total number of electronic components and batteries

March 9, 2026 | Page 5/16

that can be used.

Constraint 2: The physical size of the chassis limits the space available for electronic components, requiring careful layout and compact component selection.

Constraint 3: The tank must operate using a battery power source, which restricts the total available power to electronic components and motors.

Constraint 4: The system uses an Arduino UNO R4 WiFi, which limits available memory, processing speed, and the number of I/O pins for controlling components.

Constraint 5: The system must interface with external hardware components (motor drivers, sensors, etc.), which restricts the types of communication interfaces and protocols that can be used.

### 2.5 Dependencies

The following dependencies identify components or modules that must function correctly or be completed before other parts of the system can operate or be tested.

Dependency 1: The tank’s onboard electronics depend on the battery to supply a stable voltage.

Dependency 2: The firing mechanism depends on the flywheel motor control circuitry to operate correctly.

Dependency 3: The video transmission system depends on the RunCam Phoenix 2 FPV camera and the 5.8 GHz video transmitter functioning properly.

Dependency 4: The power distribution system must be implemented before the electronics and motors can be safely tested.

Dependency 5: The motor control system must be completed before the drive system can be tested.

Dependency 6: The camera and transmitter module must be installed before the video transmission system can be tested.

March 9, 2026 | Page 6/16

## 3. Requirements

### 3.1 Functional Requirements

Describes the functions the product shall be able to perform

Req# | Requirement | Comments | Date Rvwd | Customer Reviewed / Approved
HRS-3.1.1 | The controller shall permit the user to remotely control the tank’s movements and features within an indoor range of at least 50 m | Control should be reliable: low latency, correct, long range, and without frequent disconnection/distortions | | Mr. Roller
HRS-3.1.2 | The controller shall provide a live video feed from the tank to a user within an indoor range of at least 50 m | Video should be reliable: low latency, correct, long range, and without frequent disconnection/distortions | | Mr. Roller
HRS-3.1.3 | The tank shall be able to move at different speeds and directions: it shall be able to go forward and backward, along with turning left and right by pivoting with tank drive mechanics. | Tank drive mechanics: turning and driving by controlling either left or right sides of the tank treads as separate units. E.g., turn left on the spot by moving left tracks backwards and right tracks forwards at full speeds | | Mr. Roller
HRS-3.1.4 | The tank shall be able to fire a Nerf foam dart at a distance of at least 10 m away from the tank. | | | Mr. Roller
HRS-3.1.5 | The tank shall have a capacity of at least 10 Nerf darts. | | | Mr. Roller
HRS-3.1.6 | The tank shall be able to fire at a maximum fire rate of at least 1 dart per second | | | Mr. Roller
HRS-3.1.7 | The tank’s turret shall be able to rotate continuously, past 360° of rotation | Continuous, infinite rotation | | Mr. Roller
March 9, 2026 | Page 7/16

HRS-3.1.8 | The tank’s turret shall be able to elevate at least 30° upwards from the base position | Base elevation could be below the horizontal (E.g. range of motion from -15° to 15°) | Mr. Roller
HRS-3.1.9 | The tank shall include a toggleable red laser beam that indicates where the turret is pointing | | Mr. Roller
HRS-3.1.10 | The tank shall be able to independently identify human targets and enter a semi-autonomous mode that tracks targets with its turret | Barrel can move and rotate to aim at identified target independent of user control | Mr. Roller

### 3.2 Hardware Requirements

Describes the hardware characteristics of the product, including electronics and structural parts

Req# | Requirement | Comments | Date Rvwd | Customer Reviewed / Approved
HRS-3.2.1 | The tank's outer body shall be made with 3D-printed parts with PLA | This includes the chassis, barrel, and rotating turret. | | Mr. Roller
HRS-3.2.2 | The tank’s internal mechanisms, including but not limited to flywheels, custom gears, and shafts, shall be made with 3D-printed parts with PETG | Parts that are moving and need to withstand pressure and heat need to be printed with strong, PETG material | | Mr. Roller
HRS-3.2.3 | The tank shall be driven on two rubber tank treads, attached to the body, that are tensioned by free-spinning wheels and powered by gears | Wheels will form the shape and guide the treads, while the gear will drive and physically shift each tread. | | Mr. Roller
HRS-3.2.4 | The tank shall have a chassis base that supports the turret and treads | Houses electronic components as well | | Mr. Roller
HRS-3.2.5 | The tank shall have a turret on top of the chassis for firing | Includes barrel, housing for electronic components | | Mr. Roller
March 9, 2026 | Page 8/16

HRS-3.2.6 | The tank shall be able to accommodate a Nerf magazine, which will be inserted on the side of the tank and can be easily removed or inserted. | 3D-printed custom magazine holder Magazine is spring loaded, containing Nerf darts | Mr. Roller
HRS-3.2.7 | The tank shall be powered by a 7.4 V 2S Li-ion Battery | | Mr. Roller
HRS-3.2.8 | The tank shall use and contain an Arduino UNO R4 microcontroller. The Arduino will control and power certain input/output devices on the tank. | | Mr. Roller
HRS-3.2.9 | The tank shall use and contain a Raspberry Pi 4 for vision processing | | Mr. Roller
HRS-3.2.10 | The tank’s Raspberry Pi 4 and Arduino Uno R4 microcontrollers shall be connected to a 5 V Buck Converter, which will be connected to the 7.4 V 2S Li-ion Battery. | | Mr. Roller
HRS-3.2.11 | The tank shall contain a 28BYJ-48 stepper motor and a ULN2003 driver board for rotating the turret | | Mr. Roller
HRS-3.2.12 | The tank shall contain an MG996R servo motor for changing the turret elevation | | Mr. Roller
HRS-3.2.13 | The tank shall contain a SG90 servo motor for pushing darts to be shot out | | Mr. Roller
HRS-3.2.14 | The tank shall use two DRV8871DDA DC motor drivers to drive the two 6V-rated JGB37-550 37mm motors for moving the tank tracks | Motors have a torque of at least 0.35 Nm and an RPM of around 100-300. | Mr. Roller
HRS-3.2.15 | The tank shall use one MOSFET to run the flywheel 130-size DC motors | Motors shall be able to reach speeds of at least 25000 rpm within 2-3 seconds, operating continuously for ≥ 60 seconds without overheating | Mr. Roller
March 9, 2026 | Page 9/16

HRS-3.2.16 | The tank shall have an nRF24L01+ PA/LNA Radio Module 2.4 GHz for receiving radio signals | | Mr. Roller
HRS-3.2.17 | The tank shall have a RunCam Phoenix 2 FPV Camera for analog video to the user | | Mr. Roller
HRS-3.2.18 | The tank shall have an Eachine TX805 5.8 GHz VTX to transmit analog video to the monitor | | Mr. Roller
HRS-3.2.19 | The tank shall have a mounted digital USB AverMedia PW313 Webcam to the turret that is connected to the Raspberry Pi 4 for vision processing | | Mr. Roller
HRS-3.2.20 | The controller shall have an Arduino Uno R4 microcontroller | | Mr. Roller
HRS-3.2.21 | The controller shall contain a USB Host Shield connecting the microcontroller to the Xbox controller | USB Host Shield powers and transfers USB data between Xbox controller and microcontroller | Mr. Roller
HRS-3.2.22 | The controller’s Arduino shall be powered by a rechargeable power bank via USB | | Mr. Roller
HRS-3.2.23 | The controller shall have a wireless Xbox controller for user control | | Mr. Roller
HRS-3.2.24 | The controller shall have an nRF24L01+ PA/LNA Radio Module 2.4 GHz for transmitting radio signals | | Mr. Roller
HRS-3.2.25 | The controller shall contain a drone SoloGood 4.3” FPV monitor for receiving and streaming live video | | Mr. Roller
HRS-3.2.26 | The controller shall contain a 3D-printed PLA casing to hold the controller’s Arduino and power bank, and shall attach the monitor from HRS-3.2.25 to the controller | | Mr. Roller
March 9, 2026 | Page 10/16

### 3.3 User Interface Requirements

Describes the characteristics of each interface between the product and its users

Req# | Requirement | Comments | Date Rvwd | Customer Reviewed / Approved
HRS-3.3.1 | The tank shall be controlled by a user-operated remote Xbox controller that sends 2.4 GHz radio signals to control the tank. | Using nRF24L01+ PA/LNA radio modules, with Arduino UNO R4s , USB Host Shield, and standard Xbox wireless controllers The user can control the tank remotely | | Mr. Roller
HRS-3.3.2 | The tank shall stream live, analog video through wireless 5.8 GHz radio signals to an FPV monitor | Monitor is attached to the controller The user can watch the live video stream of the tank while they are controlling it | | Mr. Roller
HRS-3.3.3 | The tank shall be able to move its treads via joystick, radio frequency remote control | Tank drive, using an arcade drive control system where one joystick controls both tank treads Left joystick on Xbox controller | | Mr. Roller
HRS-3.3.4 | The tank shall be able to spin the flywheels when the user holds a trigger down on a radio frequency remote controller. | Flywheels will spin at different speeds based on how much the trigger is held down Left trigger on Xbox controller | | Mr. Roller
HRS-3.3.5 | The tank shall be able to shoot a dart when the user presses a button on a radio frequency remote controller. If the user holds the button, the tank shall be able to continuously fire darts. This feature will only work if flywheels are activated as outlined in HRS-3.3.4 | Right trigger on Xbox controller | | Mr. Roller
March 9, 2026 | Page 11/16

HRS-3.3.6 | The turret on the tank shall be able to rotate when the user moves the joystick of a radio frequency remote control left and right. The barrel on the tank shall be able to move up and down when the user moves the same joystick up and down. | Left/right yaw movement and up/down pitch movement on same joystick Right joystick on Xbox controller | Mr. Roller
HRS-3.3.7 | The tank shall be able to toggle a laser on or off with a radio frequency remote controller. The laser should indicate where the dart will hit. | Face button X on the Xbox controller | Mr. Roller
HRS-3.3.8 | The tank shall be able to enter and exit an autonomous mode once a user toggles a button on a radio frequency remote controller. The autonomous mode allows the tank to move and aim at targets independent of user control, but it will not be able to fire. | Face button A on the Xbox controller | Mr. Roller
HRS-3.3.9 | The tank shall automatically power off and cease movement if it loses communication with the remote controller | If signals become distorted or the tank stops receiving signals, such as if something breaks or the tank goes out of range, the tank stops all movements | Mr. Roller
HRS-3.3.10 | The tank shall have a physical on/off switch that allows users to power/start the tank and power off the tank. | Switch to connect or disconnect battery | Mr. Roller
HRS-3.3.11 | The tank shall be able to fire Nerf darts at users and non-user targets and hit them | Physical user-system interaction | Mr. Roller

### 3.4 Hardware Interfaces

Describes the internal and external communication within the product and external systems

March 9, 2026 | Page 12/16

Req# | Requirement | Comments | Date Rvwd | Customer Reviewed / Approved
HRS-3.4.1 | The tank’s Arduino microcontroller shall drive both DRV8871DDA DC motor drivers with a PWM signal, which in turn will drive 2 6V-rated JGB37-550 37mm motors connected to gears, which will drive the tank treads | | | Mr. Roller
HRS-3.4.2 | The tank’s Arduino microcontroller shall drive the MOSFET with a PWM signal, which will drive two 130-Size High-RPM DC Motors, which will be connected to the flywheels. | | | Mr. Roller
HRS-3.4.3 | The tank’s Arduino microcontroller shall drive the laser module with a digital output signal | | | Mr. Roller
HRS-3.4.4 | The Arduino microcontroller shall control a stepper driver that will drive a stepper motor that will be used to rotate the turret | Logic inputs from the microcontroller into the driver determining speed, direction, enabling, step resolution Driver controls motor by phase power switching that connects 5V to ground on specified phases, individual ends of the motor coils. | | Mr. Roller
HRS-3.4.5 | The tank’s Arduino microcontroller shall drive a servo motor with a PWM signal that will change the elevation of the barrel. | | | Mr. Roller
HRS-3.4.6 | The tank's Arduino microcontroller shall drive a servo motor with a PWM signal that will push the dart into the flywheels | | | Mr. Roller
HRS-3.4.5 | The tank’s Arduino UNO R4 communicates with the Raspberry Pi 4 by Serial UART over USB | | | Mr. Roller
March 9, 2026 | Page 13/16

HRS-3.4.7 | The tank shall have a digital webcam connected to a Raspberry Pi 4 via USB for vision processing. | | Mr. Roller
HRS-3.4.8 | The tank’s Arduino microcontroller shall receive and interpret radio signals with an nRF24L01+PA+LNA radio module by SPI | | Mr. Roller
HRS-3.4.9 | The controller’s Arduino microcontroller shall transmit and package radio signals with an nRF24L01+PA/LNA radio module by SPI | | Mr. Roller
HRS-3.4.10 | The tank’s radio module shall receive transmitted radio signals from the controller’s radio module through wireless 2.4 GHz radio signals | Radio waves will be modulated and customized data packets Antenna-to-antenna communication | Mr. Roller
HRS-3.4.11 | The controller’s Arduino microcontroller shall interface with a USB Host Shield by SPI | Note: both the radio module and host shield will need to share some SPI pins on the controller’s microcontroller, but differ in address pins | Mr. Roller
HRS-3.4.12 | The controller’s USB Host Shield will connect the Xbox Controller to the microcontroller by USB | | Mr. Roller
HRS3.4.13 | The tank shall have an FPV camera connected to a 5.8 GHz VTX transmitter | Camera sends analog composite video to the VTX | Mr. Roller
HRS3.4.14 | The tank’s video transmitter will send 5.8 GHz video signal to an FPV monitor on the controller | Analog video transmitted as radio waves Monitor and VTX need to be set to be on the same channel (frequency) VTX can switch power of signal (25 mw, 200 mW, 600 mW, 800 mW), changing range, power usage, and signal integrity | Mr. Roller
March 9, 2026 | Page 14/16

## 4. Requirements Confirmation/Stakeholder sign-off

Include documentation of the approval or confirmation of the requirements here. For example:

Meeting Date | Attendees (name and role) | Comments
02/26/26 | Designer Bryan, Designer Bruce, Manager Mr.Roller, Customer | Confirmed project proposition

## APPENDIX

## Appendix A. Definitions, Acronyms, and Abbreviations

Term/Abbreviation | Definition/Meaning
MOSFET | Metal-Oxide-Semiconductor Field-Effect Transistor: an electronic switch used to control high-current devices like motors.
PWM | Pulse Width Modulation: a technique to control motor speed by varying the duty cycle of a digital signal.
FPV | First-Person View: a system where a camera on the tank transmits live video to goggles or a monitor.
DC | Direct Current: a type of electrical current that flows in one direction, commonly used to power electronics
RF | Radio Frequency: electromagnetic waves used for wireless communication
GND | Ground: the reference point in an electrical circuit from which voltages are measured and a common return path for current.
VCC | Positive Voltage Supply: the positive voltage supply in a circuit that powers components like microcontrollers and sensors.
RPM | Rotations per minute: a measure of how fast a motor or wheel spins, indicating speed or rotational velocity.
PETG | Polyethylene Terephthalate Glycol: a strong thermoplastic filament used in 3D printing
PLA | Polylactic Acid: a simple thermoplastic filament used in 3D printing
VTX | Video Transmitter: a device that sends live video
SPI | Serial Peripheral Interface: a fast, full-duplex, synchronous 4-wire serial communication protocol
March 9, 2026 | Page 15/16

USB | Universal Serial Bus: the standard technology for connecting, communicating, and powering devices like computers, phones, and peripherals

## Appendix B. References

https://docs.arduino.cc/hardware/

https://docs.cirkitdesigner.com/component/7115dd0c-9076-1603-96e1-f4f66aa483df/main.a42f6ff8de31b a9a.js (https://docs.cirkitdesigner.com/component/7115dd0c-9076-1603-96e1-f4f66aa483df/main.a42f6ff8de31ba9a.js)

https://robocraze.com/collections/gear-motors

https://www.raspberrypi.com/

https://www.electronics-tutorials.ws/transistor/tran_6.html

https://www.orientalmotor.com/stepper-motors/technology/stepper-motor-basics.html

https://docs.sparkfun.com/SparkFun_USB-C_Host_Shield/introduction/#:~:text=The%20USB%20%2DC %20Host%20Shield%20can%20interface,Arduino%20library%20for%20the%20USB%20Host%20Shield (https://docs.sparkfun.com/SparkFun_USB-C_Host_Shield/introduction/)

https://epicfpv.ca/products/runcam-phoenix-2-spv5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 (https://epicfpv.ca/products/runcam-phoenix-2-spv5?variant=50127013183774&country=CA&currency=CAD)

https://gemini.google.com/

https://chatgpt.com/

March 9, 2026 | Page 16/16

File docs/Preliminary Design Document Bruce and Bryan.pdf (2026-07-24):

Sentinel Preliminary Design Document

# Preliminary Design Document

# Sentinel Version 1.0

# Bryan Zhang, Bruce Zhang

# Tuesday, March 31, 2026

___________________________________________________________________________________
March 31, 2026 | Page 1/39

Table of Contents
1. INTRODUCTION | 3
1.1 Project Overview | 3
2. PRODUCT DESIGN | 3
2.1 Block Diagram | 4
2.2 Sub-Circuit Descriptions | 5
2.2.1 Circuit #1 Tank | 5
2.2.1.1 Sub-Circuit #1 Tank Power Supply | 5
2.2.1.2 Sub-Circuit #2 Tank Tracks | 8
2.2.1.3 Sub-Circuit #3 Tank Flywheel Shooting | 9
2.2.1.4 Sub-Circuit #4 Tank Turret Rotation | 10
2.2.1.5 Sub-Circuit #5 Tank Dart Shover | 12
2.2.1.6 Sub-Circuit #6 Tank Barrel Elevation | 12
2.2.1.7 Sub-Circuit #7 Tank Laser Beam | 13
2.2.1.8 Sub-Circuit #8 Tank Vision Processing | 14
2.2.2 Circuit #2 Tank-Controller Interface | 15
2.2.2.1 Sub-Circuit #9 Tank-Controller Live Video | 15
2.2.2.2 Sub-Circuit #10 Tank-Controller Radio | 17
2.2.3 Circuit #3 Controller | 19
2.2.3.1 Sub-Circuit #11 Controller Power Supply | 19
2.2.3.2 Sub-Circuit #12 Controller Gamepad | 20
2.3 Product Interfaces | 23
2.3.1 Controller Internal Interfaces | 23
2.3.1.1 Interface #1: Arduino UNO R4 (U2) to USB Host Shield (U3) | 23
2.3.1.2 Interface #2: Arduino UNO R4 (U2) to nRF24L01 Adapter (U4) to nRF24L01+PA+LNA (U6) | 24
2.3.1.3 Interface #3: Power (Battery BT1 to Arduino U2) | 25
2.3.2 Controller External Interfaces | 25
2.3.2.1 Interface #4: Xbox Controller (U5) to USB Host Shield (U3) | 25
2.3.2.2 Interface #5: Arduino Programming (U2) | 25
2.3.3 Tank Internal Interfaces | 25
2.3.3.1 Interface #6: Arduino UNO R4 (U11) to Motor Drivers (U14, U17) | 25
2.3.3.2 Interface #7: Arduino UNO R4 (U11) to ULN2003 (U8) and BYJ-48 (M2) | 26
2.3.3.3 Interface #8: Arduino UNO R4 (U11) to Servo Motors (M1, M3) | 27
2.3.3.4 Interface #9: Arduino UNO R4 (U11) to nRF24L01 Adapter (U13) to nRF24L01+PA+LNA (U15) 27
2.3.3.5 Interface #10: Arduino UNO R4 (U11) to Size-130 DC Motors (M6, M7) via MOSFET (Q1) | 28
2.3.3.6 Interface #11: Arduino UNO R4 (U11) to Laser Module (LD1) | 29
2.3.3.7 Interface #12: Arduino UNO R4 (U11) to Raspberry Pi 4 (U7) | 29
2.3.3.8 Interface #13: Power Circuit (BT2 to F1 to SW1 to Distribution) | 29
2.3.3.9 Interface #14: FPV Camera (U12) and VTX Transmitter (U9) | 30
2.3.4 Tank External Interfaces | 31
2.3.4.1 Interface #15: Raspberry Pi 4 (U7) - Webcam (U10) | 31
2.3.4.2 Interface #16: Arduino Programming (U11) | 31
2.3.4.3 Interface #17: Raspberry Pi Programming (U7) | 31
2.3.5 Controller-Tank Interfaces | 32
2.3.5.1 Interface #18: FPV Video Downlink to FPV Monitor | 32
2.3.5.2 Interface #19: nRF24L01 Wireless Link | 32
3. SCHEDULING | 32
3.1 Tasks | 32
3.2 Gantt Chart Schedule | 33
APPENDIX | 34
Appendix A. Schematic | 34
Appendix B. Parts List | 36
Appendix C. Resources | 39
March 31, 2026 | Page 2/39

# 1. Introduction

## 1.1 Project Overview

The Sentinel is a remotely operated robotic toy tank designed to combine entertainment and practical engineering in a single platform. Intended for hobbyists, students, and anyone curious about robotics, the Sentinel replicates many features of a real tank: rubber-tracked drive powered by two independent 6V JGB37-550 DC gear motors, a continuously rotating turret driven by a 28BYJ-48 stepper motor, an MG996R servo-controlled barrel with adjustable elevation, and a flywheel-based Nerf dart launcher capable of firing at up to 2 darts per second. The tank is constructed primarily from 3D-printed PLA and PETG components, housing all electronics within a compact chassis powered by a single 7.4V 2S Li-ion battery.

The operator controls the tank through a wired Xbox One controller attached to a custom 3D-printed handheld controller unit, which communicates wirelessly with the tank over a 2.4 GHz
nRF24L01+PA+LNA radio link. Simultaneously, the operator receives a live first-person video feed transmitted wirelessly at 5.8 GHz from a RunCam Phoenix 2 FPV camera mounted on the tank to a SoloGood FPV monitor attached to the controller — allowing the tank to be driven effectively from far away and out of direct line of sight. The controller unit is built around an Arduino UNO R4 microcontroller paired with a USB Host Shield, while the tank itself is controlled by a second Arduino UNO R4 responsible for all motor, servo, and actuator outputs.

Beyond manual operation, the Sentinel also features a semi-autonomous targeting mode powered by a Raspberry Pi 4 onboard the tank. Using a PW313 USB webcam and the OpenCV computer vision library, the Pi continuously processes live video frames to detect and track human targets in real time using a MobileNet-SSD detection model and SORT tracking algorithm. When autonomous mode is activated, the Pi commands the Arduino to rotate and elevate the turret toward the nearest identified target automatically, while still requiring the operator to manually pull the trigger to fire — preventing unintended behaviour. A red KY-008 laser module mounted on the barrel further aids aiming precision and can be toggled on and off by the operator at any time.

A full Hardware Requirements Specification (HRS) was written prior to this document and is available for reference, detailing all functional, hardware, and interface requirements agreed upon with the project stakeholder. This Preliminary Design Document (PDD) builds on those requirements with detailed sub-circuit descriptions, interface definitions, component-level calculations, and a project schedule covering assembly through to final testing.

March 31, 2026 | Page 3/39

# 2. Product Design

## 2.1 Block Diagram

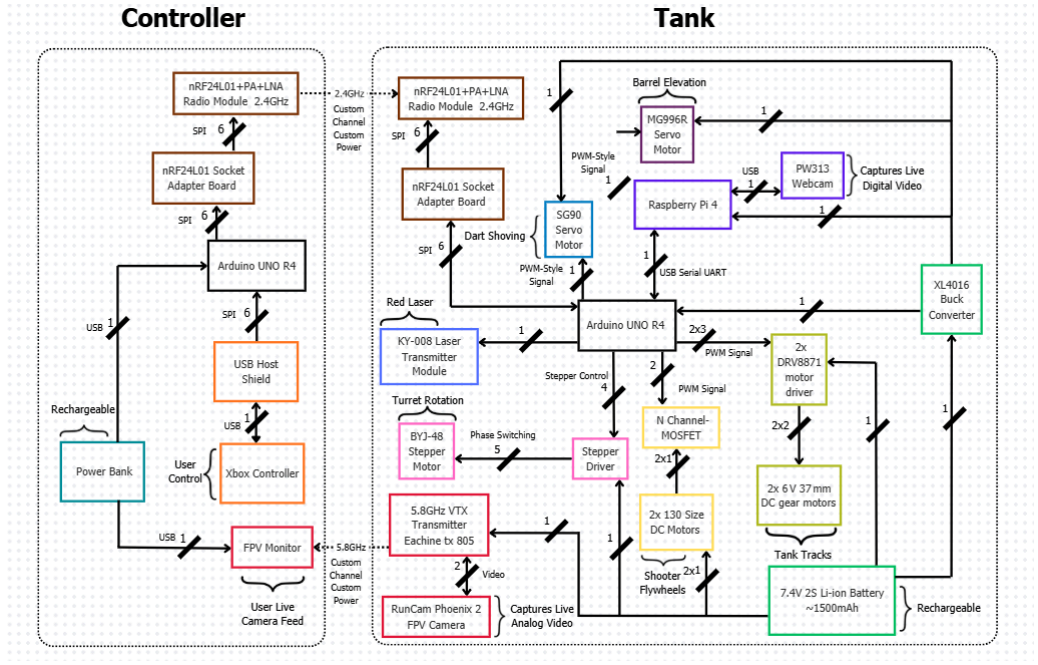
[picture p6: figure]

## 2.2 Sub-Circuit Descriptions

### 2.2.1 Circuit #1 Tank

### 2.2.1.1 Sub-Circuit #1 Tank Power Supply

The tank’s power supply is designated around a single rechargeable 7.4 V (2S) Li-ion battery, which

March 31, 2026 | Page 4/39

provides the power to all subsystems on the tank, including the drive motors, the control electronics, the turret system and the laser module.

The rechargeable 7.4 V 2S Li-ion battery connects to the rest of the circuit. Through a SS24 Toggle switch, the user can turn on and off power to the tank circuit. For safety, through a replaceable 15 A fuse, the circuit will break if the current exceeds 15 A to prevent damage to other circuit components.

A XL4016 8 A buck converter is used in the power sub-circuit to step down the battery voltage from 7.4 V to a stable 5 V, which is required by both the Arduino and the Raspberry Pi. These components are sensitive to voltage levels, and supplying them directly with the battery voltage would damage them or cause unstable operation. The buck converter ensures a consistent output voltage even when the battery voltage fluctuates under load, such as when the motors are running. Additionally, buck converters are highly efficient (typically 85–95%), meaning very little energy is lost as heat compared to linear regulators. This improves overall system efficiency and helps extend battery life. By isolating the low-voltage electronics from the high-current motor supply and providing both stable voltage and adequate current, the buck converter contributes to a more stable and reliable control system.

To ensure the battery and buck converter can meet system demands, the current draw of each major component is estimated and summed.

Part | Current Estimation | Source | Quantity | Rated Voltage (v)
6 V 56:1 37 mm JGB37-550 DC motor | Stall Current: 3 A | Source (https://www.amazon.ca/JGB37-550-Mounting-Torque-Geared-Eccentric/dp/B0BK35WYWB?th=1) | 2 | 6
130 size high RPM DC motors | Stall Current: 500 mA max | Source (https://www.farnell.com/datasheets/1863913.pdf) | 2 | 4.5 - 9
Arduino UNO R4 | Current: 97 mA -101 mA | Source (https://www.programmingelectronics.com/r4-wifi/) | 1 | 5
SG90 Servo | Current max: < 600 mA | Source (https://www.kjell.com/globalassets/mediaassets/701916_87897_datasheet_en.pdf) | 1 | 4.8 - 6
MG996R Servo | Running Current: 500 mA Stall Current: 2.5 A | Source (https://www.handsontec.com/dataspecs/motor_fan/MG996R.pdf) | 1 | 4.8 - 7.2
Raspberry Pi 4 | Recommended Current: 3 A | Source (https://pip-assets.raspberrypi.com/categories/545-raspberry-pi-4-model-b/documents/RP-008341-DS-1-raspberry-pi-4-datasheet.pdf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) | 1 | 5
AverMedia PW313 webcam | Max current: 500 mA (USB 2.0) | Source (https://www.avermedia.com/product-detail/PW313) | 1 | 5
5.8GHz VTX Transmitter Eachine tx 805 + | VTX Transmitter Current: | Source (https://www.rcgroups.com/forums/showthread.php) | 1 | 7 - 24
March 31, 2026 | Page 5/39

| 800 mW: around 350 mA
Runcam Phoenix 2 FPV Camera | Camera Running Current: around 200 mA | Source (https://www.runcam.com/download/Phoenix2/Phoenix_2_Manual.pdf?utm) | 1 | 5-36
BYJ-48 Stepper Motor | 300 mA during startup or load changes | Source (https://www.ic-components.com/blog/28BYJ-48-Stepper-Motor-Wiring,Speed,and-Applications.jsp) | 1 | Minimum 5
KY-008 laser module | 20-40 mA | Source (https://www.espboards.dev/sensors/ky-008/) | 1 | 5

The overall current draw of the system can be estimated by summing the consumption of all subsystems and grouping them by their operating voltage rails. The 5 V logic rail is the most critical in terms of stability, as it powers the Raspberry Pi 4, Arduino UNO R4, AverMedia PW313 webcam, MG996R servo, SG90 servo, nRF24L01+PA+LNA, and BYJ-48 stepper motor. Their combined current draw is approximately 3 A (Pi) + 0.1 A (Arduino) + 0.05 mA (nRF24L01+PA+LNA in RX mode) + 0.2–0.5 A (webcam) + 0.3 A (stepper) + 0.3–0.6 A (SG90 servo) + 0.6–1.5 A (MG996R servo), giving a subtotal of 4.5–6 A at 5 V. Because the XL4016 8 A Buck Converter has a max current rating of 8 A, it can sufficiently power all the 5 V components with additional headroom to ensure reliable operation and prevent overheating or brownouts.

The actuator and motor subsystems represent the largest current demand in the system because of their high torque and speed requirements. The two 6 V JGB37-550 37 mm DC gear motors draw at max approximately 6 A combined, while the two 130-size DC motors contribute approximately 1 A total. The MG996R servo adds up to 2.5 A in stall conditions, and the SG90 servo contributes up to 0.6 A peak current. When combined, these high-current motors draw approximately 5-6 A under typical operation and up to 10 A in worst-case conditions, particularly during motor startup or servo stall events. These transient spikes are important for design considerations, as they can cause voltage dips if the power distribution system is undersized.

The FPV and transmission subsystem adds a smaller but continuous load. The Eachine TX805 VTX draws approximately 350 mA at 800 mW transmission power, while the RunCam Phoenix 2 camera draws around 200 mA. Combined, this subsystem contributes approximately 0.6–1 A of continuous current draw. Although relatively small compared to the motors, it remains significant due to its constant operation and sensitivity to voltage instability.

Overall, the system is expected to draw approximately 9–10 A during normal operation, with a potential peak demand of 14 A under worst-case simultaneous loading conditions across motors, servos, and processing hardware.

The system is powered by a single 7.4 V (2S) Li-ion battery, which serves as the main energy source for all subsystems. The battery itself can sustain the heavy current draw; however, it will likely have a short battery life. Given the 7.4 V 5000 mAh 18650 2S Li-ion battery, the max capacity is 5000 mAh and the discharge rate is 20 C, so the max current can be calculated with the following:

Max current = Capacity × Discℎarge C Rating ≈ 5 Aℎ x 20 C ≈ 100 A

March 31, 2026 | Page 6/39

The max current the battery can source being 100 A is well above the estimate of how much current we need to draw; however, to prevent accidental damage to any components in case high current is drawn, a 15 A fuse is placed right next to the battery.

However, since different components require different operating voltages, a regulated power distribution system is necessary to ensure safe and stable operation.

A 5 V regulated rail is required for all logic and low-voltage electronics, including the Raspberry Pi 4, Arduino UNO R4, nRF24L01+PA+LNA radio module, webcam, and BYJ-48 stepper motor. These components are highly sensitive to voltage fluctuations, particularly the Raspberry Pi, which requires a stable 5 V supply and can experience data corruption or resets if voltage drops occur. Additionally, the two servo motors, which are also rated at around 4.8–6 V, will be using this 5 V power, as being powered directly from the Arduino 5 V would damage the Arduino due to its current draw and being powered directly from the 7.4 V Li-ion cell would damage the servos. A high-current buck converter, the XL4016 8 A Buck Converter, is therefore used to step down the 7.4 V battery supply to a stable 5 V output, ensuring consistent operation even under fluctuating motor loads.

A separate 7.4 V rail is required for the DC motors because of their higher voltage requirement. The 37 mm gear motors are rated at 6 V, while the size-130 motors are assumed to function with 3–9 V. This rail must be capable of delivering high transient currents, particularly during motor startup and servo stall events, so all of these components are directly powered from the battery. The FPV system operates partially outside the regulated rails. The Eachine TX805 VTX accepts a wide input range of 7–24 V and is therefore powered directly from the 7.4 V battery supply. This reduces conversion losses and simplifies power distribution for the high-frequency transmission system. The RunCam Phoenix 2 camera can operate either from 5 V or a higher voltage range (up to 36 V), but in this system it is powered through the VTX’s 5 V output.

Overall, the power architecture is structured around a single battery source with multiple regulated outputs. The separation into 5 V logic and low-voltage motors and 7.4 V heavy-duty actuation ensures that high-current motor loads do not interfere with sensitive electronics, improving system stability, reducing electrical noise, and maintaining consistent performance across all subsystems.

### 2.2.1.2 Sub-Circuit #2 Tank Tracks

The tank tracks subcircuit is responsible for controlling the movement of the tank. The sub-circuit includes two 37 mm JGB37-550 metal gear DC motors and two DRV8871 motor drivers to control the speed and direction of the motors.

The DRV8871 motor driver contains a single H-bridge, which allows control of one motor. Each motor is connected to its own driver module, with the outputs supplying current directly from the battery.

March 31, 2026 | Page 7/39
IN1/OUT1 | IN2/OUT2 | Result for Motor
LOW | LOW | Coast/Off
LOW | HIGH | Spin Backward
HIGH | LOW | Spin Forward

Direction control is achieved using the input pins of the motor driver. Because both output pins connect to the positive and negative terminals of the motor, setting the driver pins HIGH or LOW offers directional controls, allowing the motors to change direction, brake, and coast. Note that because all motors are identical (no such thing as left or right motors), one of the two drivetrain motors will be inverted through software as they are mirrored (pointed in opposite directions, so they spin in reverse relative to each other).

Since each motor can be controlled independently, the tank can turn by varying the motion of each tread. For example, to turn right on the spot, the tank drives the left tread forward and the right tread in reverse. Speed control of the tank is achieved by using
PWM signals, which are applied to the motor
driver’s PWM input.

V

avg = Duty Cycle × V
supply
PWM controls the speed of the motors by varying the average voltage delivered to the motors. Using PWM, the tank can turn while moving by slowing down tracks. For example, the tank can turn right while moving forward by slowing down the right
tank tread.

The torque required to move the tank depends on

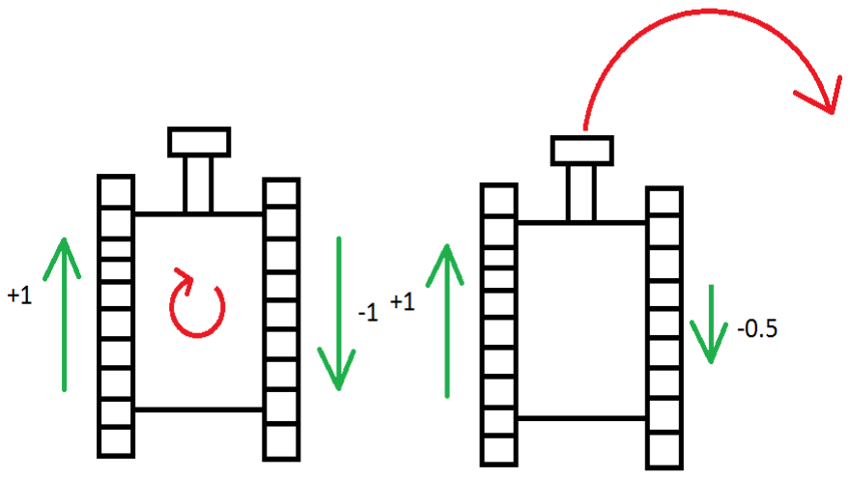
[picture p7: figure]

its mass. Taking into account the components like the motors, battery, Nerf elements, Arduino, Raspberry Pi, Cameras, and the PLA tank chassis the estimated weight of the tank is around 2.3kg. The force required to move the tank is distributed between the two motors reducing the load on each motor. The torque requirement per motor can be estimated with the following:

τ = r × F

Where τ is the torque, r is radius of the drive wheel (around 3 cm), and F is the force required to move the tank

The force can be estimated using

F = m × g × µ ≈ 2. 3 kg × 9. 81 m/s

2
× 0. 5 ≈ 11. 3 N

Where m is the mass, g is the gravitational acceleration (9.8 m/s²), and µ is the friction coefficient (around 0.5 for rubber tracks on a smooth surface)

Therefore, the required torque is:

τ = 0. 03 m · 11. 3 N ≈ 0. 34 N·m

Since each motor only provides half the total driving force, the required torque per motor is approximately 0.17 N·m under ideal conditions. However, in practice this number should be multiplied by 2-3 times because of real world variables such as starting friction, turning resistance, and different driving surfaces. This line of reasoning results in the requirement that each motor should have a torque of at least 0.51 N·m, or around 5 kgf·cm, for safe measures. As such, the 6 V 56:1 37 mm JGB37-550 DC motors, which have a rated torque of 5.0 5 kgf·cm, are perfect for this application.

March 31, 2026 | Page 8/39
HIGH | HIGH | Brake

The drive subsystem uses two 6 V 37 mm DC gear motors (≈100 RPM, ~5 kg·cm usable torque) paired with two DRV8871 motor driver modules. Each driver safely handles up to 3.6 A per motor and supports PWM speed control and bidirectional operation. Fortunately, the JGB37‑550 DC motors draw up to 3 A at stall, falling within this requirement. This combination provides sufficient torque and electrical compatibility while remaining cost‑effective and within the current limits of the control system.

Additionally, the system is powered by a 7.4 V battery; however, due to the very low internal voltage drop of approximately 0.2 V across the DRV8871 motor driver, the effective voltage supplied to the motors is nearly equal to the battery voltage, around 7.2 V at stall current. By selecting a motor rated for 6 V operation, the motor still operates safely within its tolerance range. The minimal voltage drop ensures the motor receives nearly full battery voltage, allowing efficient performance, responsive acceleration, and sufficient torque output without significant power loss.

### 2.2.1.3 Sub-Circuit #3 Tank Flywheel Shooting

The tank’s flywheels are the key part that allows the tank to serve its primary function of shooting Nerf darts. This subcircuit can be split into two main parts: the motor drive circuit and the Arduino PWM control circuit.

The flywheel mechanism consists of two 130-size high-RPM DC motors, each attached to a 3D-printed PLA flywheel. These motors are connected in parallel, ensuring that both motors receive the full supply voltage from the battery. This is important because DC motor speed is approximately proportional to the applied voltage:

ω ∝ V

ω = rotational speed

V = voltage

By wiring the motors in parallel, both motors operate at maximum designed speed, which is necessary to maintain sufficient flywheel velocity to launch a Nerf dart.

The positive terminals of both motors are connected to the
battery positive. The negative terminals are connected to the
Drain of an N-Channel MOSFET (IRLZ44N). A MOSFET (Metal-Oxide-Semiconductor Field-Effect Transistor), in this case, acts as an electronic switch that allows a low-power control signal to turn a higher-current device, like a motor, on or off. A flyback diode is placed across the motors to protect the MOSFET from voltage spikes caused by the motors. When the motors are suddenly turned off they can produce a reverse voltage spike, which the diode safely deals with.

When voltage is applied through the MOSFET Gate, a conductive channel is created between the Drain and Source, allowing current to flow through the motors. The MOSFET is chosen because our design does not require bidirectional control, which makes the MOSFET the more efficient option over a H-Bridge Motor Driver. The MOSFET

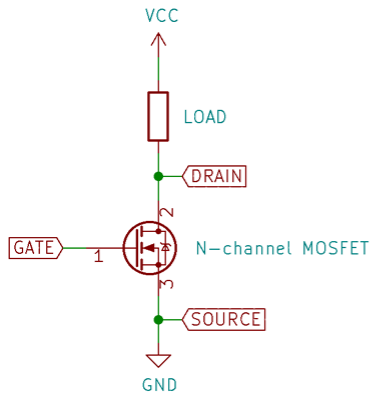
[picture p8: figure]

March 31, 2026 | Page 9/39

is also directly compatible with Arduino PWM signals and generates less heat while still being able to handle the high current required by the motors.

The Gate of the MOSFET is connected to an Arduino Uno R4 PWM pin through a 220Ω resistor. This resistor limits current to the Gate and protects the Arduino. A 10KΩ pull down resistor is then connected between the Gate and ground to ensure that the MOSFET remains OFF when no signal is present. This prevents unintended motor activation due to a floating gate.

The Arduino controls motor speed using Pulse Width Modulation (PWM).

Vavg = Duty Cycle × Vsupply

PWM rapidly switches the MOSFET on and off at a fixed frequency to control the average voltage supplied to the motors. This allows the user to control the rotational speed of the motors and thus the speed at which the Nerf darts are launched.

### 2.2.1.4 Sub-Circuit #4 Tank Turret Rotation

A BYJ-48 stepper motor, driven by a ULN2003 stepper motor driver, is used to precisely control the rotation of the entire turret. The idea is that the stepper motor is attached to the turret and drives a gear that is linked with a stationary sprocket on the base of the tank. By rotating the stepper motor, the entire turret will rotate along with it.

Stepper motors, known for their precision, have an open-loop control system by moving the motor shaft in small, discrete angles known as steps. According to the datasheet (https://www.mouser.com/datasheet/2/758/stepd-01-data-sheet-1143075.pdf?srsltid=AfmBOorL6QEq7 SdzeHiJ8wRkhsh2NAUvU2LsQwxwKVCoroCEr7jz4MgW), (https://www.mouser.com/datasheet/2/758/stepd-01-data-sheet-1143075.pdf) the BYJ-48 is a 4-phased motor with a 1:64 internal gear reduction, with a stride angle of 5.625°/64: each step rotates the shaft by 0.088°, with ~4096 steps for a full rotation. Unlike DC motors, stepper motors move in phases—the BYJ-48 has four internal coils, or electromagnets, that can be activated. Each time the right coils are powered, the rotor, which has permanent magnets, moves the shaft by one step. To achieve continuous, complete rotation, 4-phase motors run a 4-step (full) or 8-step (half) sequence to sequentially power the coils in the right order. Because of the nature of the step-by-step

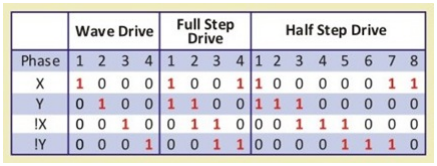
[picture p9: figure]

movement, the stepper motor is able to achieve great positional open-loop control. By sending signals to all four of the coils, the motor is able to rotate to any position as desired, with relative accuracy.

The ULN2003 driver itself needs to power the BYJ-48, and not the Arduino, because the motor coils on the BYJ-48 draw more current than the GPIO pins on the Arduino UNO R4 can supply—the GPIO pins on the UNO R4 can only safely supply up to 8 mA, while the BYJ-48 runs on 5 V with an internal resistance of 50 Ω, resulting in a 100 mA current draw per phase (https://docs.arduino.cc/resources/datasheets/ABX00087-datasheet.pdf,https://www.mouser.com/datasheet/2/758/stepd-01-data-sheet-1143075.pdf?srsltid=AfmBOorL6QEq7S dzeHiJ8wRkhsh2NAUvU2LsQwxwKVCoroCEr7jz4MgW). (https://www.mouser.com/datasheet/2/758/stepd-01-data-sheet-1143075.pdf) The ULN2003, on the other hand, includes

March 31, 2026 | Page 10/39

transistors in a Darlington array (transistors paired together to combine their strength) to draw a higher current directly from the power supply, with each transistor handling up to 500 mA (https://www.hadex.cz/spec/m513.pdf), switching the motor coils safely.

To wire the circuit, the stepper motor connects its 5-pin connector directly into the ULN2003 driver board. Then, the driver connects its four IN pins to four of the Arduino D pins. To power the driver, the VIN will be connected directly to the 5 V power supply, while it must also share a common ground with the Arduino microcontroller.

By using the Stepper library, the stepper motor can be programmed to move to precise steps by using stepper.step(int steps) and can be programmed to move at different speeds using stepper.setSpeed(int speed). If required, the AccelStep library can be used for finer control over phasing, speed, and acceleration.

### 2.2.1.5 Sub-Circuit #5 Tank Dart Shover

An SG90 servo is connected to a mechanism that is able to hit nerf darts into the flywheels so that they can be launched out. The servo will be controlled by the Arduino Uno R4 microcontroller in the tank, programmed to oscillate between 0 degrees and 90 degrees whenever the user is holding down the trigger. The SG90 servo requires 3 wires: a 5 V input, a common ground, and a PWM output signal. Because the current draw of the servo can
reach up to 500 mA, the power should be
fed directly from the 5 V buck converter
and power supply, and the ground should be shared with the Arduino ground, while the PWM is connected to the Arduino.

The PWM control on the servo is regulated by the Servo library on the Arduino. Using servo.write(0) and servo.write(90) sends a custom PWM signal to the servo—a duty cycle of 1.5/20 tells the servo to rotate to 0°, while a duty cycle of 2/20 tells the servo to rotate to 90°—causing the internal gears in the servo to spin the final motor shaft to 0 degrees and 90 degrees, respectively,
relative to the initial orientation of the
internal gears. While being held, the

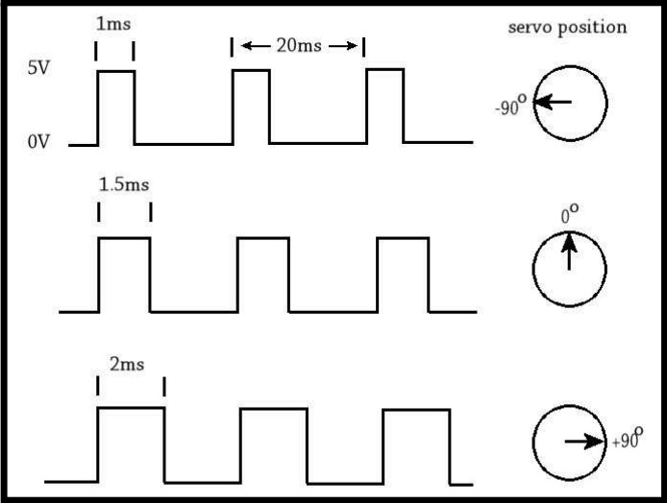
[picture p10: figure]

trigger will activate an oscillation of the servo, oscillating between upright (90 degrees) and flat (0

March 31, 2026 | Page 11/39
ULN2003 Driver Pin | Arduino Uno R4 Pin
IN1 | D8
IN2 | D9
IN3 | D10
IN4 | D11

ULN2003 Driver
Pin

Connect to

VCC | 5V
GND | GND

degrees) at periodic intervals that will be optimized through testing. This oscillation will allow Nerf darts to fall into the loading chamber and then get shoved into the flywheel system for shooting by a push-block mechanism attached to the servo arm, shooting automatically. Note that in the SG90 datasheet (http://www.ee.ic.ac.uk/pcheung/teaching/DE1_EE/stores/sg90_datasheet.pdf), the servo can travel at a maximum angular velocity of 60° / 0.1 s, so a 90° rotation outlined here could theoretically take only 150 ms, or a bit more than 300 ms for a full back-and-forth cycle. However, to buffer the timing to include reversing the direction of the motor in addition to letting the Nerf dart fall into the chamber, the servo will only likely run a half-cycle at around 250 ms or a bit over 500 ms for a full cycle, allowing a max fire rate of around 2 darts per second. Additionally, once the trigger is released, the oscillation will stop, and the servo will be programmed to reset to 0 degrees to prepare for the next cycle.

### 2.2.1.6 Sub-Circuit #6 Tank Barrel Elevation

To elevate the barrel and attain the HRS requirement of 30 degrees, the barrel of the turret, which will be attached to the flywheel system, must be able to independently raise and lower its pitch by an MG996R servo motor. Because of mechanical constraints of shoving the nerf dart into the flywheels at a steep angle, the servo only needs to bring the barrel up and down between around +15° and -15° relative to the horizontal. This requires that the servo be placed horizontally and use its precision to reach those angles through PWM control. Unlike the SG90, the MG996R can only rotate 120°, from -60° to 60°, but because the requirements do not necessitate that much range of motion, the MG996R is more than enough. Mechanically, the servo will need to lift the barrel and flywheels up and down through a channel in the turret. As the datasheet (https://www.handsontec.com/dataspecs/motor_fan/MG996R.pdf) mentions, the MG996R servo can hold a maximum stall torque of 9.4 kgf·cm at 4.8 V, meaning that it can support a 9.4 kg load 1 cm away. Although the centre of gravity of the barrel mechanism will be further away than 1 cm, the mass of the mechanism will also be less than 9.4 kg. Even at 10 cm away, the servo will still be able to support 940 g of load; fortunately, the barrel and the flywheels are only approximately 400 g - 600 g. If the servo fails to support this load, an additional servo may be added. Like the SG90, as outlined in subcircuit 2.2.1.5, the servo requires a power signal connected directly to the power supply, the PWM signal being processed by the Servo library through the Arduino, and a common ground shared with both the power supply and the Arduino.

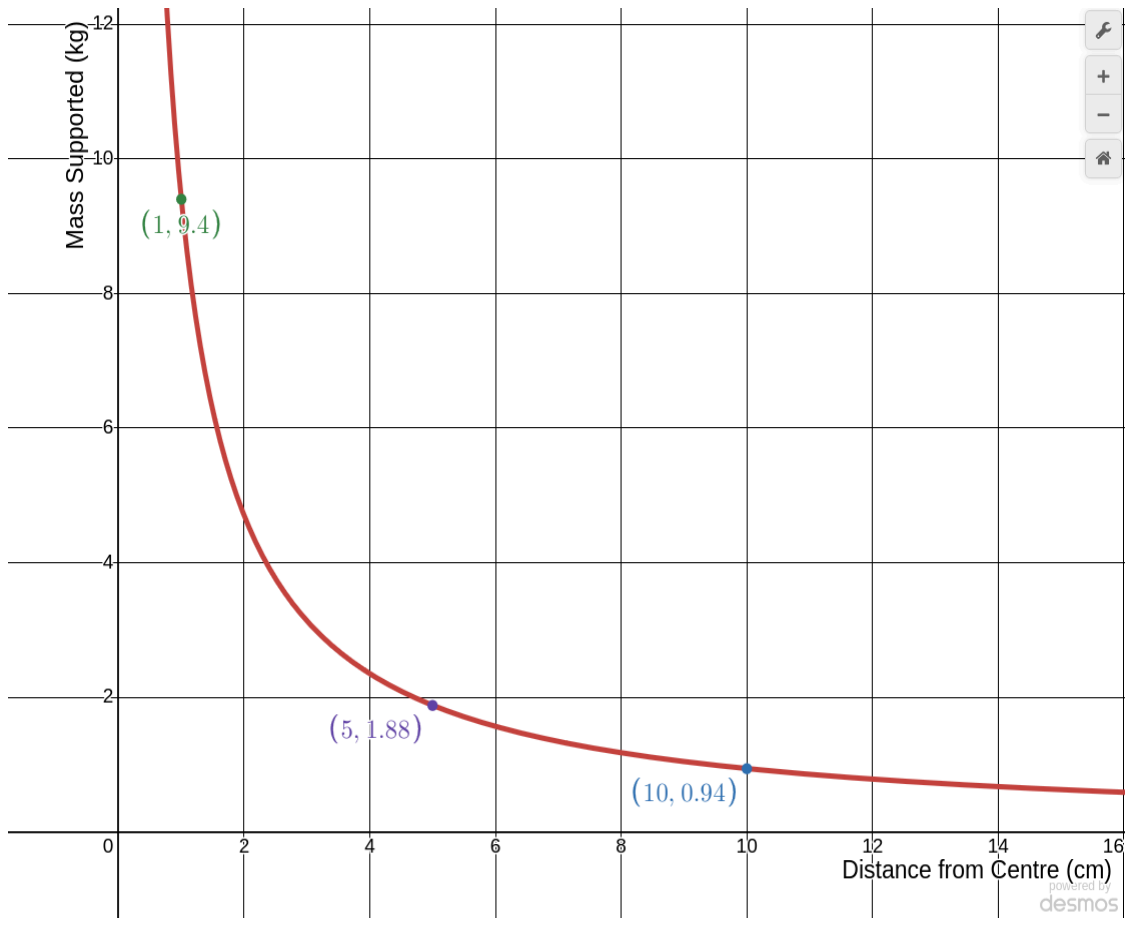
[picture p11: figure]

March 31, 2026 | Page 12/39

### 2.2.1.7 Sub-Circuit #7 Tank Laser Beam

The laser module improves the user’s aiming accuracy while also enhancing the overall functionality and intimidation factor of the tank. A KY-008 Laser Transmitter Module is mounted on the tank barrel to indicate where the Nerf dart is expected to land. The red laser is controlled by the user through the “X” button on the Xbox controller, allowing it to be toggled on and off as needed.

The KY-008 laser module (datasheet) (https://www.espboards.dev/sensors/ky-008/) operates at 5 V DC and typically draws approximately 20–40 mA of current.

The module has three pins: VCC, GND, and Signal. The VCC pin is connected to the Arduino’s 5 V supply, while the GND pin is connected to the common ground. The Signal pin is connected to a digital output pin on the Arduino.

When the Arduino outputs a HIGH signal, the laser is turned on; when the signal is LOW, the laser is turned off. This allows the laser to be easily controlled in synchronization with user input from the Xbox controller.

Since the current draw of the laser module can approach or exceed the recommended current limits of an Arduino I/O pin, a current-limiting resistor is included in series with the signal line to protect the microcontroller and ensure safe operation.

### 2.2.1.8 Sub-Circuit #8 Tank Vision Processing

The vision processing subcircuit is centred around the Raspberry Pi 4, which acts as a high-level processor for image analysis. Connected to the Pi through USB are the Arduino UNO R4 and an AverMedia PW313 webcam. The camera captures live images from the tank and sends them to the Raspberry Pi 4. Then, the Pi runs computer vision algorithms using OpenCV and other libraries to process these frames—detecting human targets in real time and finding out their position relative to the tank. Based on this analysis, the Pi generates relevant information, such as object position or targeting offsets, and transmits this data to the Arduino over a USB connection. From this data, the Arduino will use algorithms to command its actuators, controlling the autonomous mode of the tank.

Electrically, the webcam connects to the Pi through a 5 V USB-A cable, powering the webcam with less than 500 mA of current through the cable. Similarly, the Arduino connects to the Pi through a USB-C to USB-A cable, although this connection will be for data only and not power. To power the Raspberry Pi 4, continuous 5 V power will come indirectly through the power supply. As the power supply is a 7.4 V battery, an external 5 V buck converter is used to step down the voltage to power the Pi. Because the Pi is running vision processing and many calculations, it can occasionally draw substantial currents, possibly up to 2 A of current at its peaks, excluding the powering of the camera itself. The buck converter will connect to the Pi either through a powered USB-C connection or directly into the Pi’s 5 V pin—USB-C is the safer option for powering the Pi but requires cutting open a USB cable and connecting the power channels to the buck converter, while powering the Pi directly through the 5 V pin bypasses any internal circuitry designed to protect the Pi.

Although this connection uses a USB cable physically, the Arduino appears to the Pi as a virtual serial device (e.g., /dev/ttyACM0), meaning the data is sent using a UART-style serial protocol encapsulated over USB. This allows the Pi to send structured bytes and data at a defined baud rate, which the Arduino reads using its serial interface; however, this USB connection also allows the Arduino to

March 31, 2026 | Page 13/39

transmit signals to the Pi—vision processing is only required in autonomous mode, so the Arduino can initiate vision processing when necessary on the Pi to offload power demand. The Arduino then processes this data for its programmed control logic, allowing it to activate its motors and other outputs. This method provides reliable, bidirectional communication while avoiding the voltage level issues of direct UART connections, since USB handles signal conditioning and protocol management internally.

The PW313 Webcam is connected to the Raspberry Pi 4 through a USB-A connection, which not only powers the webcam but also allows the Pi to interface with the camera using the USB Video Class (UVC protocol). When connected, the camera is recognized by the Raspberry Pi’s Linux operating system as a video device (e.g., /dev/video0), allowing software libraries such as OpenCV to access a continuous stream of image frames. Internally, the webcam captures raw image data from its sensor, compresses it, and transmits it as high-speed USB packets to the Pi. The Raspberry Pi then processes the video, decoding the video into individual frames and then executing object detection and tracking algorithms through OpenCV. For example, humans will be detected using the MobileNet-SSD pretrained deep-learning model, and they will be tracked by a SORT (Simple Online and Realtime Tracking) algorithm to extrapolate object movement from data. To find relevant parameters of humans, like their distance or angle from the camera, the 2D bounding boxes will be extrapolated into 3D positions by assuming average human height and width for targets and using trigonometry, mapping, and camera calibration. Approximating the 3D pose of the targets will be sufficient for aiming the turret—because there is only one camera capable of detecting objects, 3D vision with depth is not exactly possible, but estimating target positions will yield some success. As such, the Raspberry Pi 4 will send basic target information like the distance and angle from the camera to the Arduino, allowing it to activate the stepper motor, servo motor, and flywheel motors to prepare to shoot at the nearest target.

### 2.2.2 Circuit #2 Tank-Controller Interface
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

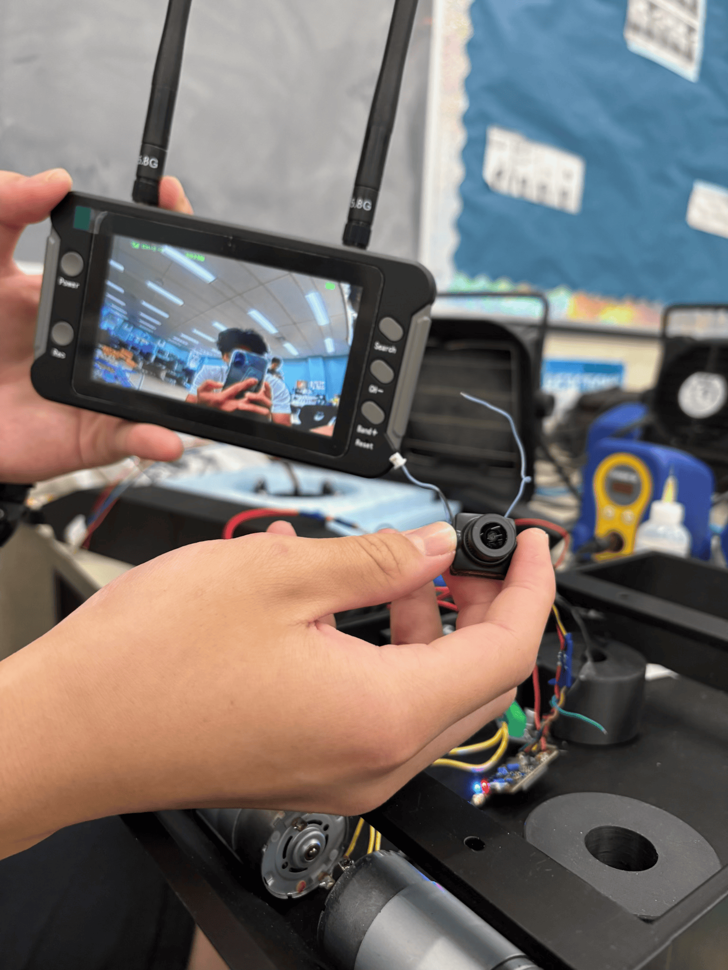
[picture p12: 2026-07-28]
demo/Monitor.png

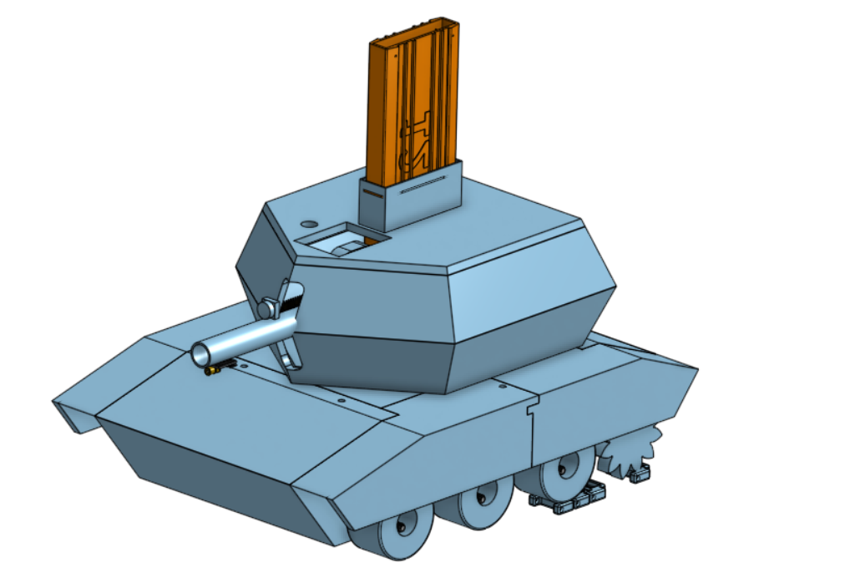
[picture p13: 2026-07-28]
demo/Tank_CAD_Render.png

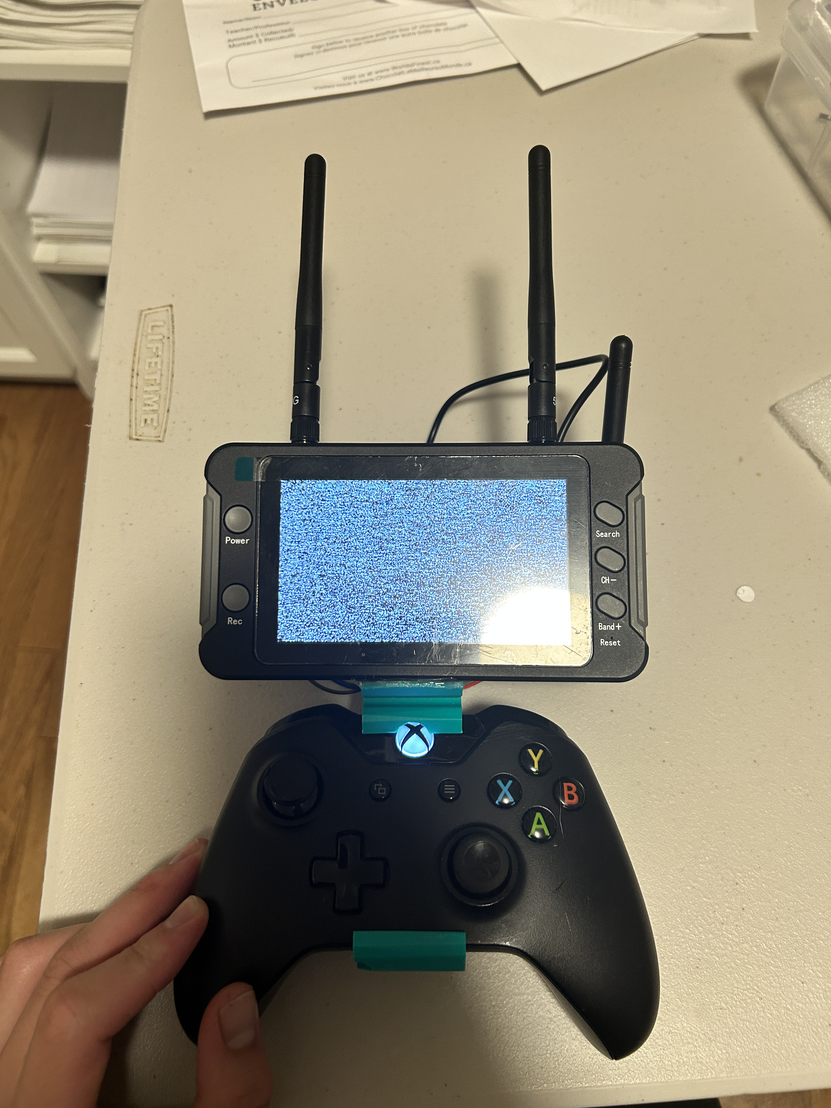
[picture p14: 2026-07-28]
demo/Controller.JPG

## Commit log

2026-07-24 Add Sentinel Tank control program
    This file contains the complete implementation of the Sentinel Tank program, which includes setup for motors, servos, radio communication, and control logic based on received radio signals.
2026-07-24 Add schematic files via upload
    [Controller.kicad_sch, Tank.kicad_sch]
2026-07-26 Expand README with additional resources
    Added additional resources including Arduino libraries, Onshape CAD project link, weekly journals, and course reflection.
2026-07-28 Enhance README with project details and resources
    Expanded project description and added features and technologies sections. Updated additional resources with links to weekly journals and CAD project.
2026-07-28 Revise CAD and Reflection section formatting
    Updated the README to improve section headings and link formatting.
